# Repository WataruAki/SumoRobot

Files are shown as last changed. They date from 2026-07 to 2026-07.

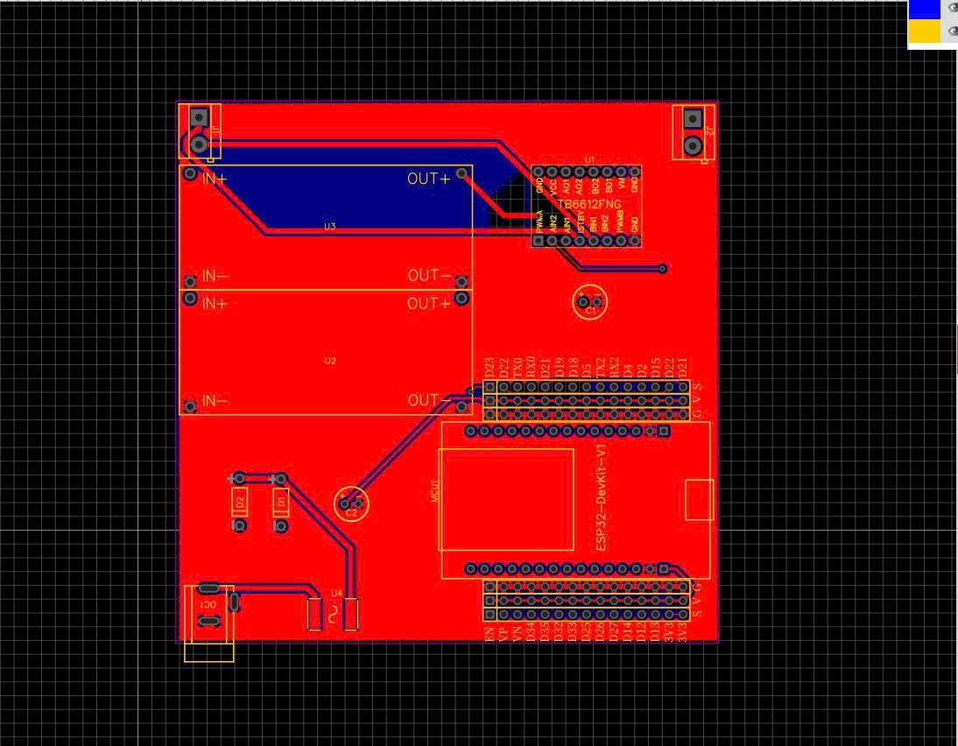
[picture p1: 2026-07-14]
hardware/SoDoMach.png

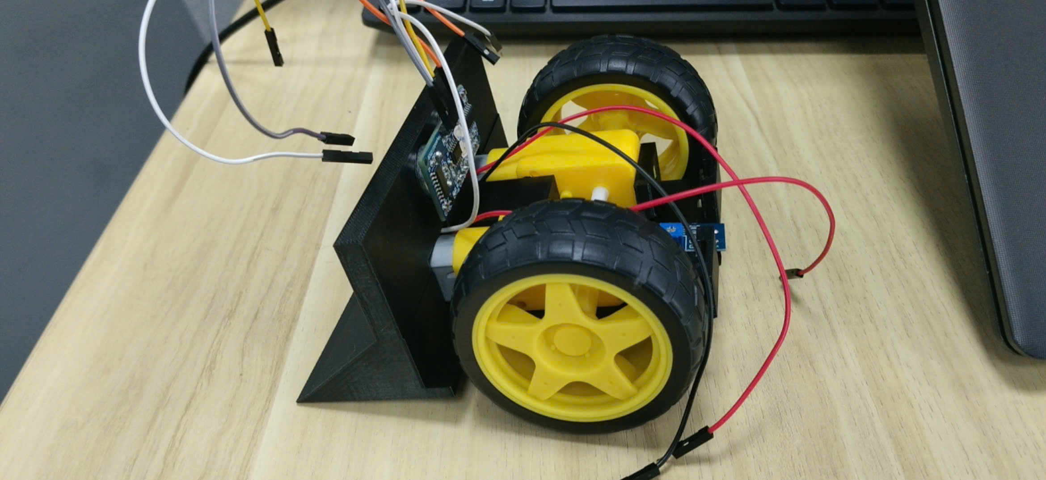
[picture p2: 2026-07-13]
docs/Minh hoa/A3.jpg

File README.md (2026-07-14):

# Sumo Robot 5-Phase - ESP32 + TB6612 + TT Motor

## Cau hinh nguon

- Pin 2S cap truc tiep vao VM cua TB6612.
- Mot LM2596 chinh 5.0 V chi cap cho ESP32 va cam bien.
- Tat ca GND noi chung.
- Khong cap chung hai motor qua LM2596 trong ban thi dau.
- ECHO cua HC-SR04 phai qua cau chia ap 5 V xuong 3.3 V.

## Anh xa GPIO

| Chuc nang | GPIO |
|---|---:|
| PWMA / AIN1 / AIN2 | 18 / 21 / 19 |
| PWMB / BIN1 / BIN2 | 5 / 22 / 23 |
| HC-SR04 TRIG / ECHO | 25 / 26 |
| Nut START | 27 |
| Cam bien bien truoc | 32 |
| TB6612 STBY | Noi co dinh 3V3 |

Kenh A duoc xem la motor trai, kenh B la motor phai. Neu mot ben quay nguoc, doi
`INVERT_LEFT_MOTOR` hoac `INVERT_RIGHT_MOTOR` thanh `true`.

## Switch RUN/STOP

- OFF = GPIO27 HIGH: cat PWM ngay va reset may trang thai ve `WAIT_START`.
- ON = GPIO27 LOW on dinh 35 ms: bat dau lai pha 1 va dem du 5 giay.
- OFF khong chi la lenh START nua; no la kill switch phan mem trong moi pha.
- Truoc khi reset/cap nguon, de switch OFF. Sau hieu lenh moi gat ON.

Serial khi gat OFF trong luc dang chay:

```text
[SWITCH OFF] Da cat motor va reset ve WAIT_START.
```

## Nam pha chinh

1. `PHASE_1_PROBING`: dung yen 5 giay, thu mau sieu am va tinh trung vi.
2. `PHASE_2_JUKE`: ne trai/phai co phan hoi, can 3 lan mat muc tieu moi dung.
3. `PHASE_3_RELOCK`: xoay tim, doi huong sau 420 ms, timeout 900 ms.
4. `PHASE_4_STRIKE`: tiep can, thu tiep xuc 100 ms, burst 80 ms.
5. `PHASE_5_RING_CONTROL`: bam muc tieu, chong neo, danh suon va thoat bien.

## Adaptive Extreme (van chi 5 pha)

- Loc median 3 mau sieu am de giam xung nhay/phan xa gia.
- Uoc luong toc do ap sat theo cm/s tu cac mau raw lien tiep.
- Can 2 mau charge lien tiep moi kich hoat ne, tranh phan ung voi mot mau nhieu.
- Khi doi thu lao nhanh trong 16-45 cm, ne trai/phai 90-140 ms roi khoa lai.
- Co cooldown 650 ms de doi thu khong the dung dong tac gia lam robot ne lien tuc.
- Random co gioi han thoi gian juke, search, contact test, burst va flank arc.
- Cac gioi han PWM, timeout motor va uu tien cam bien bien khong thay doi.

Day la cac trang thai con nam trong pha 5, khong phai them pha thu 6.

## Cam bien line - quyen uu tien cao nhat

- GPIO32 dung `INPUT_PULLUP`, cam bien nen cap 3V3.
- Khi khoi dong, dat robot de cam bien nam tren phan SAN DEN.
- Code lay 80 mau de hoc muc san den va tu suy ra muc vach trang doi nghich.
- Neu tin hieu dao qua 6 lan trong luc calibration, code bao loi va dung muc fallback.
- Gap vach thi ngat chien thuat ngay lap tuc, khong debounce de tranh bo lo vach 2.5 cm.
- Chi roi trang thai thoat bien sau khi da roi vach on dinh 20 ms.

Serial khoi dong dung phai co dang:

```text
[LINE] OK: floor=1, white=0, transitions=0.
```

Neu robot khoi dong khi cam bien dang nam tren vach trang, calibration se bi dao va
robot co the xem san den la vach. Luon dat tren san den truoc khi cap nguon/reset.

## Chien thuat chong neo / quat hut

- Tiep can o PWM 175.
- Tai khoang cach tiep xuc, thu day 100 ms o PWM 190.
- Burst them 80 ms o PWM 205.
- Neu muc tieu van sat dau xe, khong ghe motor: lui 65 ms.
- Chay cung danh suon 220 ms, luan phien trai/phai.
- Sau cung danh suon, quay lai pha khoa muc tieu.

Khong co encoder/cam bien dong nen day la phan loai bao thu. Robot xem tinh huong
"muc tieu van sat sau 180 ms" la nguy co neo, khong phai bang chung chac chan.

## Gioi han PWM voi pin 2S

- Search: 90
- Juke: 190
- Approach: 175
- Contact test: 190
- Attack burst: 205 trong toi da 80 ms
- Escape: 160
- Flank arc: 75 / 185

PWM 255 chi duoc dung cho short-brake cua TB6612, khong dung de keo TT lien tuc.

## Serial debug

Mo Serial Monitor o 115200 baud. Code in trang thai moi 300 ms, khong in moi
vong loop de tranh lam cham robot.

Vi du:

```text
[DBG] t=8350 state=P3_RELOCK sub=- US=24cm seen/lost=2/0 close=85cm/s charge=1 edgeRaw/white=1/0 start=0 motorL/R=90/-90
```

- `state`: pha hien tai.
- `sub`: trang thai con cua pha 4/5.
- `US`: khoang cach sieu am gan nhat; `-1` la timeout.
- `seen/lost`: so mau thay/mat lien tiep.
- `close`: toc do ap sat uoc luong; so duong la dang tien gan.
- `charge`: 1 khi da xac nhan doi thu lao nhanh.
- `edgeRaw/white`: muc raw hien tai / muc da hoc cho vach trang.
- `start`: muc logic cong tac START; ON thuong la 0.
- `motorL/R`: lenh PWM co dau cua motor trai/phai.

Dat `DEBUG_SERIAL=false` sau khi hieu chinh xong neu muon tat log dinh ky.

## Hieu chinh truoc tran

1. Chinh LM2596 = 5.0 V truoc khi cam ESP32.
2. Kiem tra hai banh tien dung chieu; sua hai bien `INVERT_*` neu can.
3. Dat robot cach vach, xac dinh `EDGE_WHITE_LEVEL` la `HIGH` hay `LOW`.
4. Cho luoi xuc vua cham vat, doc Serial va sua `CONTACT_DISTANCE_CM`.
5. Thu edge reverse tu toc do thap; giam `EDGE_REVERSE_MAX_MS` neu lui qua xa.
6. Thu flank arc khi robot o giua san; giam `FLANK_ARC_MS` neu cung qua rong.
7. Kiem tra pin day 8.4 V; motor va TB6612 khong duoc nong nhanh.
8. Khi nap code qua USB, tranh dong thoi cap nguon 5 V nguoc vao cong USB neu mach
   chua co power-ORing.

## Trang thai xac minh

Da kiem tra cu phap voi Arduino-ESP32 Core 2.x va 3.x. Code chi dung HC-SR04 de
phat hien doi thu, khong can thu vien ToF/I2C. Van can bien dich tren dung board
package va thu tai thuc te truoc thi dau.

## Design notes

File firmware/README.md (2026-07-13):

# Robot Sumo Tự Hành – ESP32 Firmware

Firmware điều khiển cho robot sumo tự hành (autonomous), chạy trên vi điều khiển ESP32. Sau khi bấm nút Start, robot hoạt động hoàn toàn tự động: dò tìm đối thủ bằng cảm biến khoảng cách, truy đuổi, tấn công đẩy, đồng thời tự né vạch biên trắng để không bị đẩy ra khỏi sân đấu.

## Mục lục
- [Tính năng chính](#tính-năng-chính)
- [Phần cứng yêu cầu](#phần-cứng-yêu-cầu)
- [Sơ đồ chân (Pinout)](#sơ-đồ-chân-pinout)
- [Thư viện cần cài đặt](#thư-viện-cần-cài-đặt)
- [Cấu hình trước khi nạp](#cấu-hình-trước-khi-nạp)
- [Nguyên lý hoạt động](#nguyên-lý-hoạt-động)
- [Nạp firmware & sử dụng](#nạp-firmware--sử-dụng)
- [Tinh chỉnh thông số](#tinh-chỉnh-thông-số)
- [Cấu trúc mã nguồn](#cấu-trúc-mã-nguồn)
- [Gỡ lỗi](#gỡ-lỗi-debug)
- [Giới hạn hiện tại](#giới-hạn-hiện-tại)

## Tính năng chính
- Máy trạng thái 7 pha mô phỏng chiến thuật thi đấu: chờ hiệu lệnh → dò tìm mở màn → né đòn đầu → khóa lại mục tiêu → tấn công → kiểm soát sân đấu
- Kết hợp cảm biến siêu âm HC-SR04 (bắt buộc) và ToF VL53L0X (tùy chọn, bật/tắt bằng một macro)
- Cơ chế **"anti-anchor"**: khi bị đối thủ ghì đứng yên, robot tự lùi ngắn rồi đánh vòng cung sang sườn thay vì cố đẩy thẳng mãi
- Tự động lùi + xoay né ngay khi cảm biến biên phát hiện vạch trắng ranh giới sân
- Ngẫu nhiên hóa chu kỳ quét siêu âm để giảm nhiễu chéo khi hai robot cùng dùng cảm biến siêu âm đối đầu nhau
- Debounce nút Start; log/telemetry chi tiết qua Serial để theo dõi và hiệu chỉnh

## Phần cứng yêu cầu
| Thành phần | Vai trò |
|---|---|
| Vi điều khiển ESP32 | Bắt buộc — dùng `esp_system.h` và API LEDC (`ledcAttach`/`ledcWrite`) |
| Cảm biến siêu âm HC-SR04 | Cảm biến khoảng cách chính để phát hiện đối thủ |
| Cảm biến ToF VL53L0X | Tùy chọn — cảm biến phụ tăng độ chính xác, bật qua macro `USE_VL53L0X` |
| Cảm biến vạch biên (ngõ ra số) | 1 cảm biến đặt chính giữa đầu robot, phát hiện vạch trắng ranh giới sân |
| Driver động cơ đôi kiểu TB6612FNG (hoặc tương đương) | Mỗi kênh gồm 1 chân PWM + 2 chân điều khiển chiều IN1/IN2 |
| 2 động cơ DC (bánh trái/phải) | Truyền động |
| Nút nhấn Start | Đấu `INPUT_PULLUP`, nhấn = mức LOW |

## Sơ đồ chân (Pinout)

| Chức năng | Hằng số | GPIO |
|---|---|---|
| Nút Start | `PIN_START_BUTTON` | 27 |
| Siêu âm – Trig | `PIN_US_TRIG` | 25 |
| Siêu âm – Echo | `PIN_US_ECHO` | 26 |
| ToF VL53L0X – SDA | `PIN_TOF_SDA` | 33 |
| ToF VL53L0X – SCL | `PIN_TOF_SCL` | 13 |
| Động cơ trái – PWM | `PIN_LEFT_PWM` | 18 |
| Động cơ trái – IN1 | `PIN_LEFT_IN1` | 21 |
| Động cơ trái – IN2 | `PIN_LEFT_IN2` | 19 |
| Động cơ phải – PWM | `PIN_RIGHT_PWM` | 5 |
| Động cơ phải – IN1 | `PIN_RIGHT_IN1` | 22 |
| Động cơ phải – IN2 | `PIN_RIGHT_IN2` | 23 |
| Cảm biến biên (giữa) | `PIN_EDGE_CENTER` | 32 |

> Cảm biến biên báo "phát hiện vạch trắng" ở mức `HIGH` (hằng số `EDGE_WHITE_LEVEL`). Nếu cảm biến của bạn xuất mức ngược lại, đổi hằng số này thành `LOW`.
>
> Nếu một bên động cơ quay ngược chiều mong muốn khi test thực tế, chỉnh `INVERT_LEFT_MOTOR` / `INVERT_RIGHT_MOTOR` thành `true` thay vì đấu lại dây động cơ.

## Thư viện cần cài đặt
- **Arduino-ESP32 core** (board package cho ESP32) — code tự nhận diện phiên bản core qua `ESP_ARDUINO_VERSION_MAJOR` để gọi đúng API LEDC (core v3+ dùng `ledcAttach`, core v2.x dùng `ledcSetup`/`ledcAttachPin`), nên tương thích cả hai dòng core phổ biến
- **Thư viện `VL53L0X`** (Pololu) — chỉ cần cài nếu bật cảm biến ToF

## Cấu hình trước khi nạp
Đầu file `Firmware.ino` có các macro/hằng số nên kiểm tra trước khi build:

```cpp
#define USE_VL53L0X 0   // đổi thành 1 nếu robot có gắn cảm biến ToF VL53L0X
```

```cpp
constexpr bool INVERT_LEFT_MOTOR  = false;
constexpr bool INVERT_RIGHT_MOTOR = false;
```

Nếu giữ `USE_VL53L0X 0`, firmware chỉ dùng cảm biến siêu âm và không cần cài thư viện VL53L0X.

## Nguyên lý hoạt động
Robot vận hành theo máy trạng thái chính gồm 7 pha:

```mermaid
stateDiagram-v2
    [*] --> WAIT_START
    WAIT_START --> PHASE_1_PROBING: nhấn nút Start
    PHASE_1_PROBING --> PHASE_2_JUKE: hết 5s dò tìm mở màn
    PHASE_2_JUKE --> PHASE_2_BRAKE: mất dấu hoặc hết giờ né
    PHASE_2_BRAKE --> PHASE_3_RELOCK: hết thời gian phanh ngắn
    PHASE_3_RELOCK --> PHASE_4_STRIKE: khóa được mục tiêu
    PHASE_3_RELOCK --> PHASE_5_RING_CONTROL: hết giờ khóa lại (900ms)
    PHASE_4_STRIKE --> PHASE_5_RING_CONTROL: kết thúc chu trình tấn công
    PHASE_5_RING_CONTROL --> PHASE_3_RELOCK: xong pha đánh sườn (anti-anchor)

    note right of PHASE_5_RING_CONTROL
        Chạm vạch biên (từ Phase 2 trở đi)
        đều nhảy về đây để lùi + xoay
        thoát biên trước khi dò tiếp
    end note
```

**1. `WAIT_START`** — Đứng yên, liên tục kiểm tra nút Start (debounce 35ms). Đây là lúc chờ trọng tài hô hiệu lệnh.

**2. `PHASE_1_PROBING`** (5 giây cố định) — Đứng yên tại chỗ, trong lúc đó liên tục quét siêu âm (và ToF nếu bật) với chu kỳ ngẫu nhiên 45–70ms để tránh nhiễu chéo. Cuối pha, tính khoảng cách trung vị (median) và % độ tin cậy để xác định có đối thủ phía trước hay không, đồng thời chọn ngẫu nhiên hướng né ban đầu (trái/phải).

**3. `PHASE_2_JUKE` → `PHASE_2_BRAKE`** — Xoay né nhanh (pivot quanh một bánh) sang hướng đã chọn để tránh cú lao đầu tiên của đối thủ. Dừng né khi cảm biến xác nhận mất dấu đối thủ (3 lần đo liên tiếp không thấy) hoặc khi chạm mốc thời gian tối đa, sau đó phanh chủ động (counter-brake) trong 15ms để triệt tiêu đà quay trước khi dò tìm lại.

**4. `PHASE_3_RELOCK`** — Xoay quét tìm lại mục tiêu: quét theo hướng đã định trong 420ms đầu, sau đó đổi hướng nếu vẫn chưa thấy. Thấy đối thủ đủ số mẫu liên tiếp (2 lần) → khóa mục tiêu, chuyển Phase 4. Quá 900ms không khóa được → chuyển Phase 5 để tìm kiếm rộng hơn.

**5. `PHASE_4_STRIKE`** — Tiến thẳng lại gần mục tiêu đã khóa; khi đủ gần (≤14cm) sẽ thử chạm nhẹ (contact test) trong 100ms để xác nhận, rồi bung lực đẩy mạnh (attack burst) trong 80ms nếu vẫn còn giữ khoảng cách chạm (≤17cm). Sau đòn đẩy: nếu đối thủ vẫn còn kề sát (bị ghì, không lùi) → chuyển sang Phase 5 ở trạng thái con đánh sườn (anti-anchor); nếu mất mục tiêu hoặc hết giờ giới hạn 650ms → cũng rơi về Phase 5 để dò tìm lại.

**6. `PHASE_5_RING_CONTROL`** — Pha "kiểm soát sân đấu" tổng quát, có 7 trạng thái con:

| Trạng thái con | Mô tả |
|---|---|
| `P5_REGULAR_TRACKING` | Xoay quét tìm mục tiêu; thấy thì tiến lại gần, đủ gần thì chuyển sang chạm thử |
| `P5_CONTACT_TEST` | Đẩy nhẹ thử chạm để xác nhận đối thủ thực sự ở trước mặt |
| `P5_ATTACK_BURST` | Bung lực đẩy mạnh trong thời gian ngắn |
| `P5_ANCHOR_ESCAPE` | Lùi nhanh để thoát tình trạng bị ghì đứng yên (đẩy mãi không đi) |
| `P5_FLANK_ARC` | Đánh vòng cung sang một bên sườn đối thủ rồi quay lại khóa mục tiêu ở Phase 3 |
| `P5_EDGE_REVERSING` | Lùi ra khỏi vạch trắng biên sân (có xác nhận đã sạch vạch) |
| `P5_EDGE_TURNING` | Xoay hướng ra xa biên trước khi quay lại dò tìm mục tiêu |

Ngoài ra, nếu vừa thấy mục tiêu rồi mất dấu đột ngột trong lúc tracking, robot sẽ "lao thẳng dự đoán" (**blind rush**, 70ms) theo quán tính trước khi chuyển sang quét tìm, thay vì dừng lại ngay lập tức.

**Ưu tiên an toàn:** kể từ khi robot bắt đầu di chuyển (Phase 2 trở đi), cảm biến biên luôn được kiểm tra trước tiên ở từng bước xử lý. Hễ phát hiện vạch trắng, robot ngắt ngay hành vi hiện tại, lùi ra xa vạch (có xác nhận đã sạch vạch), rồi xoay hướng thoát ra — hướng xoay đổi luân phiên mỗi lần để không lặp lại đúng một góc bị kẹt — trước khi quay lại dò tìm đối thủ. Riêng `WAIT_START` và 5 giây `PHASE_1_PROBING`, robot đứng yên hoàn toàn nên không cần kiểm tra biên.

## Nạp firmware & sử dụng
1. Mở `Firmware.ino` bằng Arduino IDE (hoặc PlatformIO)
2. Cài board package ESP32 nếu chưa có, chọn đúng board trong menu Tools → Board
3. Chọn đúng cổng COM (cài driver USB-to-serial nếu cần)
4. (Tùy chọn) Cài thư viện `VL53L0X` và sửa `USE_VL53L0X` thành `1` nếu robot có cảm biến ToF
5. Nạp firmware
6. Mở Serial Monitor, tốc độ **115200 baud**, để theo dõi log
7. Đặt robot vào sân, chờ hiệu lệnh trọng tài rồi nhấn nút Start — robot tự đứng yên đúng 5 giây trước khi bắt đầu di chuyển

## Tinh chỉnh thông số
Toàn bộ tham số thời gian (ms) và tốc độ PWM (0–255) được khai báo `constexpr` ở đầu file, có thể chỉnh trực tiếp mà không ảnh hưởng logic chương trình:

| Nhóm | Ví dụ hằng số | Ý nghĩa |
|---|---|---|
| Ngưỡng khoảng cách hợp lệ | `US_MIN_CM`/`US_MAX_CM`, `TOF_MIN_MM`/`TOF_MAX_MM` | Vùng khoảng cách được xem là "có đối thủ" |
| Ngưỡng chạm/tấn công | `CONTACT_DISTANCE_CM`, `CONTACT_HOLD_DISTANCE_CM` | Khoảng cách kích hoạt chạm thử / giữ đẩy |
| Thời lượng từng hành vi | `JUKE_MIN_MS`/`MAX_MS`, `STRIKE_TOTAL_TIMEOUT_MS`, `RELOCK_TIMEOUT_MS`, `FLANK_ARC_MS`... | Giới hạn thời gian mỗi hành vi |
| Tốc độ động cơ | `PWM_SEARCH`, `PWM_APPROACH`, `PWM_ATTACK_BURST`, `PWM_FLANK_SLOW`/`FAST`... | Tốc độ PWM cho từng hành vi cụ thể |

Các giá trị này phụ thuộc nhiều vào ma sát mặt sân, công suất động cơ và điện áp pin thực tế, nên cần tinh chỉnh dần và thử trực tiếp trên sân thi đấu.

## Cấu trúc mã nguồn
| Nhóm chức năng | Hàm liên quan |
|---|---|
| Điều khiển động cơ | `setMotor`, `shortBrakeMotor`, `setupMotorPwm`, `writeMotorPwm`, `motorsDrive`, `stopMotors`, `executeJuke`, `executeCounterBrake`, `executeSearchTurn` |
| Đọc cảm biến thô | `readUltrasonicCm`, `readToFMm`, `edgeDetected`, `startButtonPressed` |
| Thống kê Phase 1 | `resetTelemetry`, `collectPhase1`, `finalizePhase1`, `medianOf`, `printTelemetry` |
| Cảm biến khi giao chiến (Phase 3–5) | `resetCombatObservation`, `updateCombatSensors`, `combatTargetSeen`, `combatDistanceCm` |
| Xử lý từng pha | `handlePhase3`, `handlePhase4`, `handlePhase5`, `enterEdgeEscape` |

## Gỡ lỗi (Debug)
Mở Serial Monitor ở **115200 baud**. Log được in dạng `[NHÃN] nội dung`, một số nhãn tiêu biểu:
- `[SAN SANG]`, `[PHASE 1]`, `[PHASE 2]`, `[PHASE 3]`, `[PHASE 3 -> 4]`, `[PHASE 4 -> 5]` — chuyển pha
- `[BIEN]` — phát hiện/thoát vạch biên sân
- `[ANTI-ANCHOR]` — kích hoạt/kết thúc pha đánh sườn khi bị ghì
- `[LOI]` — lỗi khởi tạo PWM hoặc không tìm thấy cảm biến ToF

Cuối `PHASE_1_PROBING`, firmware in bảng telemetry: số mẫu siêu âm/ToF hợp lệ trên tổng số lần đo, có phát hiện đối thủ hay không, % độ tin cậy, khoảng cách trung vị và hướng né đã chọn — rất hữu ích để kiểm tra cảm biến trước khi thi đấu.

## Giới hạn hiện tại
- Chỉ có **một** cảm biến biên đặt giữa robot, không phân biệt được vạch biên nằm bên trái hay bên phải khi chạm, nên phản ứng thoát biên luôn theo một kiểu lùi + xoay cố định
- Các cú xoay (search turn, edge turn...) là **điều khiển theo thời gian** (time-based, vòng hở), không có hồi tiếp từ IMU/encoder, nên góc xoay thực tế có thể lệch theo điện áp pin và độ ma sát mặt sân
- Cảm biến ToF VL53L0X chỉ là tùy chọn (mặc định tắt); khi tắt, mọi quyết định hoàn toàn dựa vào cảm biến siêu âm

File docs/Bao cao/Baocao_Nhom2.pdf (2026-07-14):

## ĐẠI HỌC QUỐC GIA HÀ NỘI

## Trường Đại học Việt Nhật

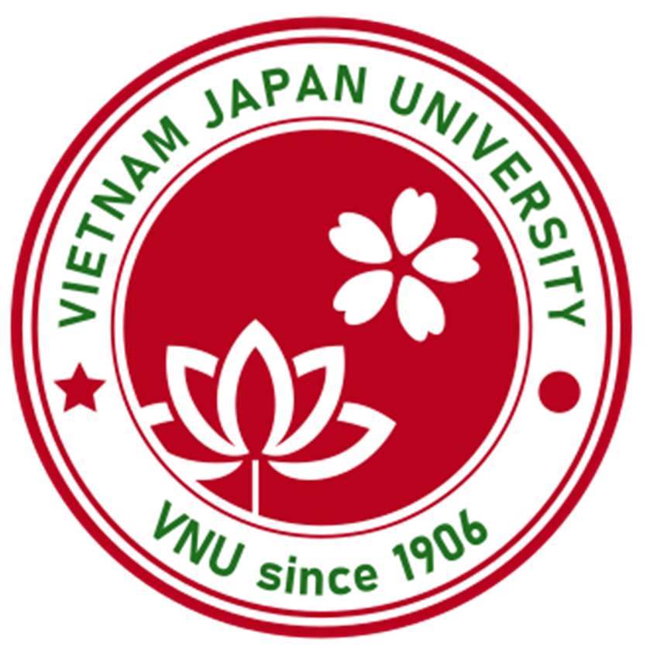
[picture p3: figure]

## BÁO CÁO BÀI THI KẾT THÚC HỌC PHẦN

## Môn: Thí nghiệm trong khoa học kĩ thuật 1

Giảng viên hướng dẫn: TS. Bùi Huy Kiên, MSc. Nguyễn Tiến Đạt

## Nhóm 2

Danh sách thành viên
1. 25112007 - Hoàng Việt Anh - Nhóm trưởng
2. 25112001 - Lê Văn Thái An
3. 25112002 - Dương Hoàng An
4. 25119064 - Lê Văn Trường

2

# Mục lục

3

4

## Lời nói đầu

Trong kỷ nguyên công nghiệp 4.0, hệ thống nhúng và Internet vạn vật đang ngày càng khẳng định vị thế cốt lõi trong việc thay đổi bộ mặt công nghệ toàn cầu. Để thích ứng và làm chủ những công nghệ tiên tiến này, việc thu hẹp khoảng cách giữa lý thuyết giảng đường và thực tiễn sản xuất là vô cùng cấp thiết. Nhận thức được tầm quan trọng đó, học phần Thí nghiệm trong Khoa học và Kỹ thuật 1 tại Trường Đại học Việt Nhật đã mang đến dự án cuối kỳ “Sumo Robot Challenge”. Đây không chỉ là một bài kiểm tra kiến thức thông thường, mà còn là một thử thách kỹ thuật toàn diện, đòi hỏi sinh viên phải tự tay trải nghiệm toàn bộ quy trình phát triển một sản phẩm công nghệ từ con số không.
Báo cáo kỹ thuật này là kết quả sau hơn một tháng nỗ lực nghiên cứu, thử nghiệm và hoàn thiện của nhóm. Thông qua việc chế tạo một robot tự hành tham gia thi đấu sumo, nhóm đã có cơ hội quý báu để cọ xát với thực tế: từ việc tối ưu hóa cấu trúc cơ khí bằng công nghệ in 3D/cắt laser, thiết kế sơ đồ nguyên lý mạch phần cứng, mạch nguồn pin Li-ion 2S, cho đến việc lập trình thuật toán máy trạng thái phức tạp nhằm điều khiển robot vận hành một cách thông minh, tự động hoàn toàn. Quá trình triển khai dự án không chỉ giúp chúng em củng cố sâu sắc chuyên môn kỹ thuật mà còn rèn luyện được các kỹ năng mềm thiết yếu để giải quyết các bài toán phát sinh trong thực tế.
Để có thể hoàn thành sản phẩm và bài báo cáo này một cách trọn vẹn, nhóm nghiên cứu xin được gửi lời cảm ơn sâu sắc nhất đến thầy TS. Bùi Huy Kiên và anh MSc. Nguyễn Tiến Đạt. Sự tận tình trong công tác giảng dạy, cùng những định hướng chuyên môn, góp ý kỹ thuật sắc bén của thầy và anh trong suốt các tuần học đã giúp nhóm vượt qua nhiều rào cản công nghệ lớn để đưa sản phẩm đi đúng hướng.
Dù đã dành nhiều thời gian đầu tư và chuẩn bị nghiêm túc, song do giới hạn về mặt thời gian cũng như kinh nghiệm thực tế, báo cáo chắc chắn không tránh khỏi những thiếu sót nhất định. Nhóm rất mong sẽ nhận được những ý kiến đóng góp, nhận xét từ thầy và anh để sản phẩm cũng như kiến thức của nhóm được hoàn thiện hơn nữa. Trân trọng cảm ơn

5

I. GIỚI THIỆU & ĐẶT VẤN ĐỀ

### 1. Bối cảnh dự án

Sumo Robot Challenge là bài tập lớn cuối học phần thí nghiệm trong khoa học và kĩ thuật 1. Nhiệm vụ của nhóm là thiết kế, chế tạo một robot tự hành hoàn chỉnh và tham gia thi đấu nhằm mục đích đẩy robot đối thủ ra khỏi sàn đấu tròn theo luật

### 2. Mục tiêu

- Cơ khí: Thiết kế, gia công khung bằng in 3D/cắt laser; tối ưu hóa trọng tâm và lực bám.
- Phần cứng: Thiết kế mạch nguồn , mạch điều khiển động cơ và tích hợp các cảm biến.
- Phần mềm: Lập trình vi điều khiển theo mô hình máy trạng thái, giúp robot tự động dò biên viền trắng và tấn công/phòng thủ khi phát hiện đối thủ.
- Kỹ năng: Quản lý mã nguồn qua GitHub, làm việc nhóm và viết báo cáo kỹ thuật.

### 3. Ràng buộc kỹ thuật

- Kích thước & Khối lượng: Diện tích chân đế khởi đầu bé hơn 12x12, khối lượng tổng bé hơn 700g
- Nguồn điện: Bắt buộc sử dụng 2 cell pin Li-ion/LiPo mắc nối tiếp (7.4 V), cấm mạch tăng áp hoặc nguồn ngoài.
- Vận hành: Tự hành hoàn toàn dựa trên cảm biến dò biên hướng xuống và cảm biến phát hiện đối thủ; cấm điều khiển bằng tay.
- An toàn: Cấm các cơ cấu gây phá hủy, gây nhiễu, hoặc sử dụng vật liệu nguy hiểm.
II. TỔNG QUAN & NGHIÊN CỨU LIÊN QUAN

### 1. Tổng quan về thể thức thi đấu Mini-Sumo

- Sàn đấu : Mặt phẳng hình tròn bằng gỗ MDF hoặc mica sơn, đường kính tiêu chuẩn 77 cm. Mặt sân được sơn màu đen nhám ít phản xạ và bao quanh bởi một vạch viền màu trắng rộng 2.5 cm ở mép ngoài cùng để làm mốc định vị biên cho cảm biến quang học.

6

- Luật thi đấu đối kháng: Hai robot đối đầu trực tiếp theo thể thức loại trực tiếp. Mỗi trận đấu diễn ra tối đa trong 3 hiệp (mỗi hiệp tối đa 3 phút). Robot giành chiến thắng 1 hiệp khi đẩy được đối thủ ra khỏi vạch trắng hoặc đối thủ tự di chuyển ra ngoài sàn đấu.
- Yêu cầu khởi động: Sau khi có hiệu lệnh của trọng tài và người điều khiển nhấn nút kích hoạt, robot bắt buộc phải cấu hình một khoảng thời gian trễ đúng 5 giây trước khi chính thức di chuyển.

### 2. Cơ sở lý thuyết

a. Thiết kế cơ khí
Ta có công thức vật lí cổ điển:
F ≤ μ ⋅ N = μ ⋅ m ⋅ g
Trong đó:
- μ: Hệ số ma sát giữa bánh xe và mặt sàn Dohyo.
- m: Khối lượng toàn bộ của robot (∼ 700 g).
- g: Gia tốc trọng trường.

Để tối đa hóa lực đẩy, bên cạnh việc lựa chọn vật liệu lốp có hệ số ma sát μ cao, giải pháp cơ khí tối ưu là phải hạ trọng tâm xuống sát mặt sàn nhất có thể nhằm tránh hiện tượng mô-men lực làm lật hoặc nhấc bổng robot khi va chạm trực diện. Khung vỏ được vẽ trên CAD và chế tạo bằng công nghệ in 3D kết hợp cắt laser giúp cấu trúc bền bỉ, hấp thụ xung lực tốt.
b. Kiến trúc phần cứng và mạch động lực

Hệ thống điện tử trên robot Sumo được xây dựng xung quanh chip xử lý trung tâm hiệu năng cao ESP32, kết hợp với hệ thống điều khiển công suất:
- Khối nguồn : Robot sử dụng hệ thống pin Li-ion 2S mắc nối tiếp. Hệ thống mạch nguồn được bọc bảo vệ cách điện tuyệt đối nhằm tránh nguy cơ ngắn mạch hoặc cháy nổ khi va chạm mạnh.
- Khối điều khiển động cơ: Sử dụng IC điều khiển động cơ DC dòng cao tích hợp chân chân kích hoạt và chế độ chờ. Vi điều khiển sử dụng chức năng điều xung ledc của ESP32 ở tần số cao 20 kHz với độ phân giải 8-bit

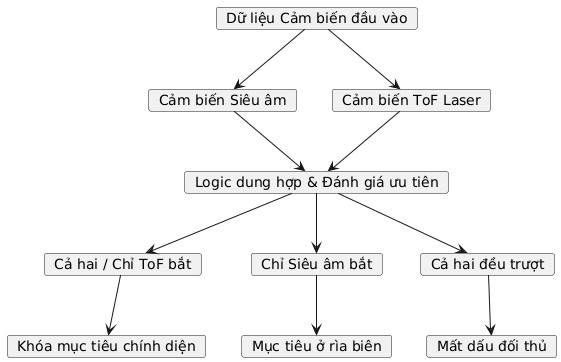
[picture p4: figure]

7

nhằm triệt tiêu tiếng rít dòng điện, giúp điều khiển tốc độ và đảo chiều động cơ.
c. Dung hợp cảm biến

Để khắc phục nhược điểm vật lý của từng loại cảm biến đơn lẻ trong môi trường thi đấu động, hệ thống sử dụng kiến trúc radar kép phối hợp:
- Cảm biến siêu âm: Đo khoảng cách góc rộng (ngưỡng hoạt động 60 cm). Ưu điểm là vùng phủ lớn nhưng độ chính xác kém và tần số lấy mẫu chậm.
- Cảm biến ToF Laser VL53L0X: Đo khoảng cách bằng thời gian bay của chùm laser tập trung (ngưỡng hoạt động 600 mm). Ưu điểm là tốc độ lấy mẫu rất cao và góc quét hẹp, đóng vai trò khóa mục tiêu ở chính diện.
- Logic dung hợp: Hệ thống đánh giá dữ liệu theo thứ tự ưu tiên: Nếu cả hai hoặc chỉ có ToF phát hiện, mục tiêu được xác định ở trạng thái khóa chính diện. Nếu chỉ có siêu âm phát hiện, mục tiêu đang nằm ở mép trái/phải. Khi cả hai đều trượt, hệ thống ghi nhận mất dấu .
d. Thuật toán trạng thái & Chiến thuật thi đấu
- Đòn nhử đầu hiệp: Ngay khi kết thúc 5 giây đếm ngược, thay vì lao thẳng trực diện, robot thực hiện pha bẻ lái chớp nhoáng. Hướng bẻ lái được thuật toán

8

chọn ngẫu nhiên để đối thủ không thể bắt bài ở các hiệp sau. Một bánh sẽ khóa hãm, bánh còn lại chạy với tốc độ cao. Đòn này lợi dụng quán tính lao tới của đối phương để lách né, đồng thời mở góc để robot phản công từ mạn sườn. Đáng chú ý, cơ chế an toàn dò vạch trắng vẫn được giữ mức ưu tiên cao nhất ngay trong pha né tránh để đảm bảo robot không vô tình tự lùi ra khỏi sân.
- Quét tìm kiếm chống nhiễu: Khi mất dấu mục tiêu, robot duy trì tốc độ xoay ổn định kết hợp đảo chiều định kỳ. Để triệt tiêu hiện tượng cộng hưởng nhiễu sóng siêu âm từ các robot khác phát ra, hệ thống áp dụng cơ chế nhiễu thời gian: chu kỳ phát xung ping lấy mẫu không cố định mà biến thiên ngẫu nhiên trong khoảng 30 - 42 ms. Việc này giúp làm sạch luồng dữ liệu đầu vào trước khi đưa qua hệ thống lọc.
- Rà góc và khóa mục tiêu: Tốc độ quét được thiết lập ở mức thấp chính là chìa khóa để triệt tiêu quán tính cơ học, giúp hệ thống không trượt lố qua mục tiêu. Khi cảm biến phát hiện vật thể, robot không vội vã tấn công mà yêu cầu một chuỗi xác nhận dữ liệu liên tiếp
- Gia tốc theo từng bậc chiến thuật : Khi mục tiêu bị khóa, robot không đột ngột tăng ga tối đa (255) ngay lập tức để tránh hiện tượng trượt bánh hoặc bốc đầu làm hổng lưỡi ủi. Thuật toán kiểm soát lực bám đường bằng cách chia sức mạnh theo từng bậc thực chiến: tiếp cận với tốc độ vừa, tăng lực tạo đà khi bắt đầu va chạm, và chỉ bùng nổ công suất ép tối đa khi cảm biến xác nhận khoảng cách dính chập.
- Cơ chế ngắt mềm dò biên ưu tiên cao: Để đảm bảo tính ổn định cao nhất cho hệ thống lõi ESP32 và tránh xung đột bộ nhớ do điều khiển động cơ bằng ngắt phần cứng, firmware sử dụng vòng lặp ưu tiên. Lệnh kiểm tra vạch trắng edgeDetected() luôn được đặt ở vị trí đầu tiên của mọi chu trình chiến đấu. Ngay khi phát hiện mép sàn, cờ hiệu lập tức kích hoạt, buộc robot hủy mọi tác vụ tấn công hiện tại để lùi khẩn cấp và bẻ góc hướng trở lại vùng trung tâm an toàn.
III. THIẾT KẾ TỔNG THỂ & PHẦN CỨNG

### 1. Thiết kế tổng thể hệ thống:

Hệ thống điều khiển Sumo Robot được cấu trúc thành một vòng lặp kín bao gồm 4 khối chức năng chính hoạt động xoay quanh vi điều khiển trung tâm ESP32:

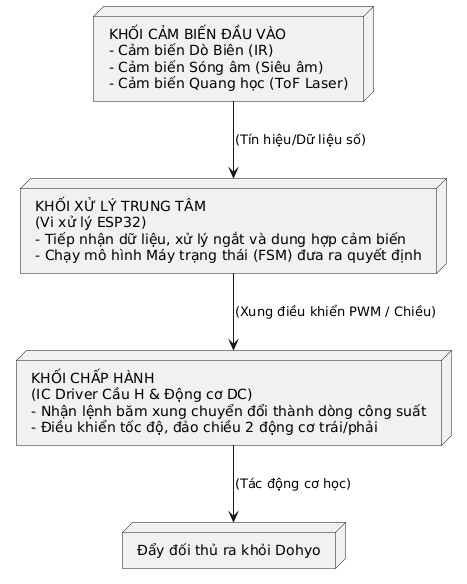
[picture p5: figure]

9

- Khối xử lý trung tâm: Đóng vai trò là “não bộ” tiếp nhận dữ liệu từ khối cảm biến, thực hiện thuật toán dung hợp dữ liệu và máy trạng thái để xuất xung điều khiển động cơ.
- Khối cảm biến: Bao gồm radar kép (Cảm biến siêu âm + ToF Laser) để phát hiện vật thể và cảm biến hồng ngoại phản xạ (IR) để phát hiện vạch biên.
- Khối chấp hành: Bao gồm IC cầu H điều khiển động cơ DC băm xung PWM và chân kích hoạt standby.
- Khối nguồn và giao tiếp ngoại vi: Pin Li-ion 2S, mạch hạ áp, nút nhấn khởi động và cổng nạp.

### 2. Thiết kế chi tiết phần cứng & Sơ đồ nối dây

10

a. Cấu hình chân vi điều khiển
STT | Chân trên mạch | GPIO | Chức năng | Ghi chú
1 | PIN_AIN1 | 25 | Điều khiển chiều quay Động cơ Trái (Hướng 1) | Kết nối khối Driver
2 | PIN_AIN2 | 26 | Điều khiển chiều quay Động cơ Trái (Hướng 2) | Kết nối khối Driver
3 | PIN_PWMA | 27 | Phát xung PWM điều khiển tốc độ Động cơ Trái | Tần số băm xung 20 kHz
4 | PIN_BIN1 | 14 | Điều khiển chiều quay Động cơ Phải (Hướng 1) | Kết nối khối Driver
5 | PIN_BIN2 | 12 | Điều khiển chiều quay Động cơ Phải (Hướng 2) | Kết nối khối Driver
6 | PIN_PWMB | 13 | Phát xung PWM điều khiển tốc độ Động cơ Phải | Tần số băm xung 20 kHz
7 | PIN_STBY | 33 | Kích hoạt hoặc ngắt chế độ chờ (Standby) của Driver | Logic HIGH để hoạt động
8 | PIN_LINE | 32 | Nhận tín hiệu số đầu vào từ cảm biến dò biên | Cấu hình ngắt phần cứng (ISR)
9 | I2C_SDA | 21 | Đường truyền dữ liệu số (Data) giao tiếp I2C | Kết nối cảm biến ToF VL53L0X
10 | I2C_SCL | 22 | Đường cấp xung nhịp (Clock) giao tiếp I2C | Kết nối cảm biến ToF VL53L0X
11 | PIN_US_TRIG | 5 | Phát xung kích hoạt đầu phát sóng siêu âm | Phát xung mức cao thời gian 10 µs
12 | PIN_US_ECHO | 18 | Thu nhận xung phản hồi tính thời gian sóng âm | Đo thời gian bằng hàm pulseIn
13 | PIN_BTN_START | 4 | Nút nhấn cơ học kích hoạt hệ thống | Khởi động chu trình đếm ngược 5 giây

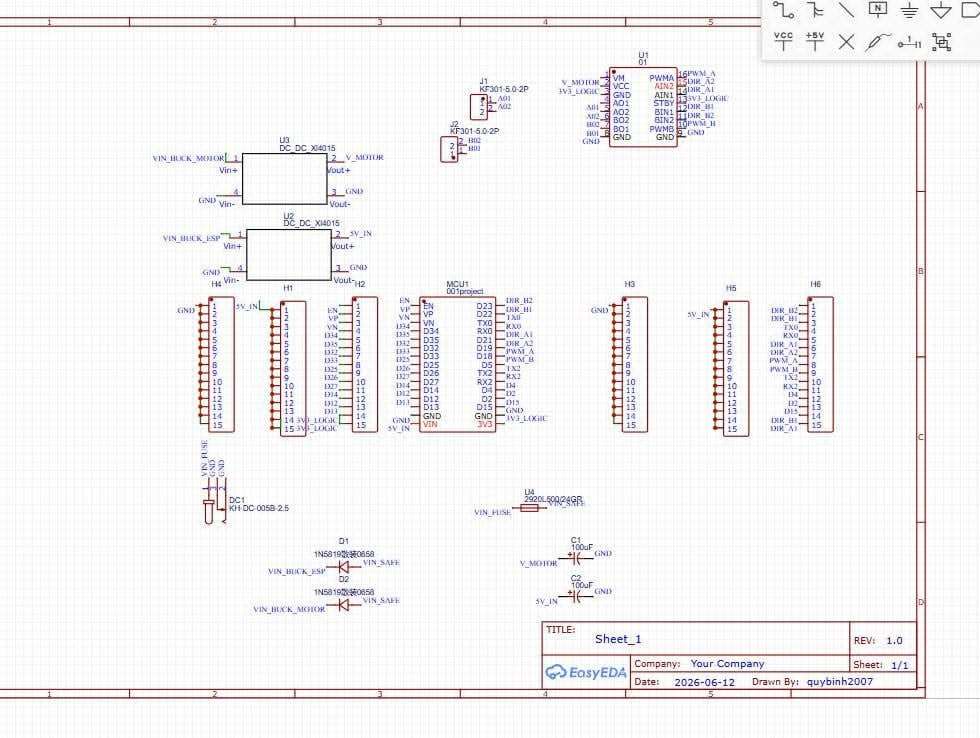
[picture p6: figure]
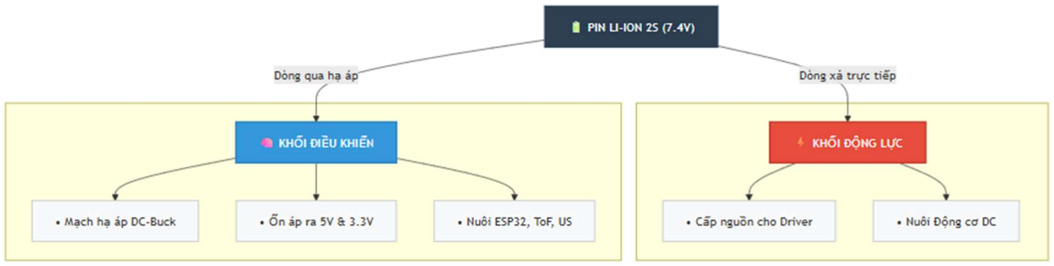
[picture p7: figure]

11

Ảnh: Sơ đồ mạch
b. Thiết kế mạch nguồn an toàn

Hệ thống nguồn tuân thủ nghiêm ngặt quy định sử dụng 2 cell pin Li-ion 18650 mắc
nối tiếp, cung cấp điện áp danh định 7.4 V (Đầy tải đạt 8.4 V). - | Đường nguồn động lực: Nguồn từ pin được dẫn trực tiếp tới chân cấp nguồn
| công suất của IC Driver để nuôi động cơ, đảm bảo lực đẩy mạnh nhất mà
không bị sụt áp hệ thống. - | Đường nguồn nuôi chip xử lý: Dòng điện qua một mạch hạ áp DC-Buck hạ
| xuống 5 V và 3.3 V ổn định để cấp phát cho ESP32, cảm biến ToF và siêu âm, tránh hiện tượng nhiễu xung ngược từ động cơ làm treo vi điều khiển.

12

### 3. Danh mục vật tư:

STT | ID | Linh kiện | Thông số kỹ thuật | SL | Chức năng
1 | U1 | Mạch điều khiển trung tâm ESP32-WROOM-32D | - SoC 32-bit Dual-core Xtensa LX6, 240 MHz. - Bộ nhớ: 520 KB SRAM, 4 MB Flash. - Tích hợp bộ tạo xung ledc PWM độ phân giải 8-bit. | 01 | Khối xử lý trung tâm, tiếp nhận cảm biến, thực hiện thuật toán dung hợp và quản lý máy trạng thái
2 | U4 | IC Driver động cơ TB6612FNG | - Driver cầu H hiệu suất cao - Nguồn động lực: 2.5 − 13.5 V - Nguồn logic: 2.7 − 5.5 V - Dòng điện: 1.2A/kênh - Tần số PWM: 100 kHz. | 01 | Nhận xung PWM 20 kHz và tín hiệu đảo chiều từ ESP32 để điều khiển độc lập tốc độ, hướng 2 động cơ.
3 | U3 | Cảm biến khoảng cách HC-SR04 | - Tần số định hướng: 40 kHz. - Điện áp hoạt động: 5V DC. - Góc quét: ≤ 15∘ - Dải đo: 2 − 60 cm. | 01 | Quét tìm kiếm đối thủ ở vùng biên diện rộng; phối hợp cùng ToF để xác định góc lệch trái/phải.
4 | S1 S2 | Cảm biến dò biên TCRT5000 | - Cặp LED bước sóng 950nm. - Khoảng cách phản xạ tối ưu: 2.5 − 12 mm. - Đầu ra số: HIGH / LOW | 02 | Đặt hướng xuống mặt sàn ở mép trước để phát hiện vạch biên trắng (rộng 2.5 cm) qua tín hiệu ngắt phần cứng.
5 | M1 M2 | Động cơ DC giảm tốc | - Hộp số giảm tốc tỉ lệ 1:48 - Tốc độ không tải:200 RPM. - Momen xoắn: 0.8 kg.cm. | 02 | Khối chấp hành cơ khí, biến đổi điện năng thành cơ năng sinh lực đẩy momen xoắn
6 | BAT1 | Pin lưu trữ Li-ion 18650 | - Cấu hình 2 cell mắc nối tiếp - Điện áp danh định: 7.4 V - Dòng xả tối đa: ≥ 10A. | 02 | Cung cấp nguồn năng lượng cho toàn mạch; đi dây trực tiếp tới mạch động lực Driver.
7 | U5 | Mạch hạ áp DC-DC Buck | - Điện áp vào: 4.5 − 28V, áp ra cố định: 5.0 V DC. - Dòng ra tối đa: 2A, hiệu suất chuyển đổi ≥ 90%. | 01 | Hạ áp từ nguồn pin 2S xuống 5V ổn định nuôi ESP32 và khối cảm biến; cách ly nhiễu back-EMF từ động cơ.
8 | SW1 | Nút nhấn khởi động | - Kiểu nút nhấn nhả, định mức: 50mA @ 12V DC. - Cấu hình điện trở kéo lên nội bộ. | 01 | Giao tiếp người - máy; kích hoạt chu trình FSM bắt đầu đếm ngược thời gian trễ 5 giây đầu trận.
9 W1 | W2 | Bánh xe | - Đường kính: 65 mm, chiều rộng: 26 mm. | 02 | Chuyển đổi chuyển động quay của động cơ thành

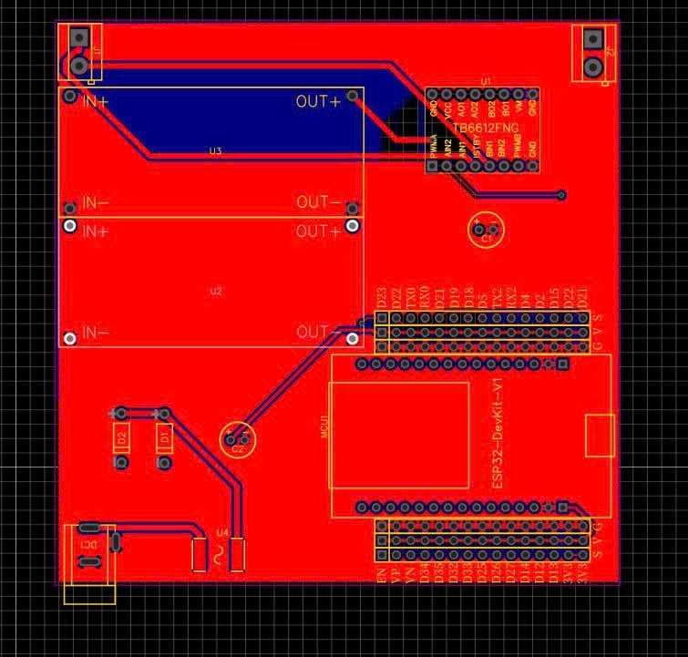
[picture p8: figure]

13

| | | - Lốp cao su lưu hóa có gai bám đường, lõi nhựa ABS. | | chuyển động tịnh tiến; tối ưu ma sát với mặt sàn gỗ MDF.
10 | PCB | Mạch in hệ thống PCB | - Vật liệu nền: Sợi thủy tinh FR4 độ dày 1.6 mm. - Độ dày lớp đồng: 1 oz (35 μm), bo mạch 2 lớp - Độ rộng đường mạch động lực cấp nguồn: ≥ 40 mil. | 01 | Tích hợp toàn bộ hệ thống đường dây kết nối, cố định các module shield, triệt tiêu dây cắm rời để tăng độ bền cơ học.
11 | T1 | Cảm biến ToF | - Công nghệ Time-of-Flight - Dải đo: 30 − 600 mm - Tốc độ lấy mẫu: 25 ms | 01 | Khóa mục tiêu chính diện, cung cấp phản hồi khoảng cách tốc độ cao

Ảnh: Bảng mạch PCB
IV. THIẾT KẾ CƠ KHÍ

### 1. Ý tưởng thiết kế cấu trúc:

- Tầng đáy: Nơi lắp đặt cặp động cơ DC giảm tốc TT bố trí đối xứng, hai bánh xe chủ động 65 mm và lưỡi ủi ở phía trước. Cặp cảm biến dò biên TCRT5000 được thiết kế gá treo hướng thẳng góc xuống mặt sàn, cách mép trước lưỡi ủi 5 mm để tối ưu tốc độ phản hồi khi chạm vạch.

14

- Tầng giữa: Khu vực bố trí khối nguồn Pin Li-ion 18650 2S. Pin được đặt nằm ngang, song song với trục bánh xe nhằm dồn trọng lượng lớn nhất vào chính giữa xe, giúp cân bằng lực tải lên cả hai bánh.
- Tầng thượng: Vị trí đặt Board mạch in hệ thống tích hợp MCU ESP32 , IC Driver TB6612FNG và module hạ áp. Cảm biến siêu âm HC-SR04 được đặt đồng trục trên một giá đỡ vát dốc góc ở mặt tiền, hướng ra phía trước để tạo thành radar kép khóa mục tiêu.
- Thiết kế lưỡi ủi chống lật
- Nguyên lý vận hành: Khi va chạm trực diện, góc vát biến lực đẩy ngang của đối thủ thành áp lực hướng xuống, ép bánh xe của robot nhóm xuống mặt sàn để tăng ma sát.
- Ràng buộc an toàn: Phần mép tiếp xúc sàn được mài tù góc, tuyệt đối không sắc bén để tuân thủ quy định an toàn của giải đấu, tránh làm xước bề mặt sàn hoặc phá hủy robot đối phương.

### 2. Phương pháp chế tạo

a. Công nghệ in 3D cho các chi tiết chịu lực phức tạp
- Vật liệu sử dụng: Nhựa PLA có độ cứng cao, co ngót nhiệt thấp, đảm bảo độ chính xác kích thước bắt vít.
- Thông số cấu hình:
Thông số | Giá trị | Mục đích
Độ dày lớp in | 0.2-0.8 mm | Đạt độ mịn bề mặt tối ưu, cân bằng giữa thời gian in và chất lượng ngoại quan.
Mật độ khối đặc | 40% | Đảm bảo độ cứng cáp cho khung vỏ mà không làm robot quá nặng, tối ưu trọng lượng.
Kiểu cấu trúc in | Gyroid | Cấu trúc tối ưu nhất trong cơ học: Giúp hấp thụ và phân tán xung lực đồng đều mọi hướng, chống nứt vỡ khi va chạm mạnh

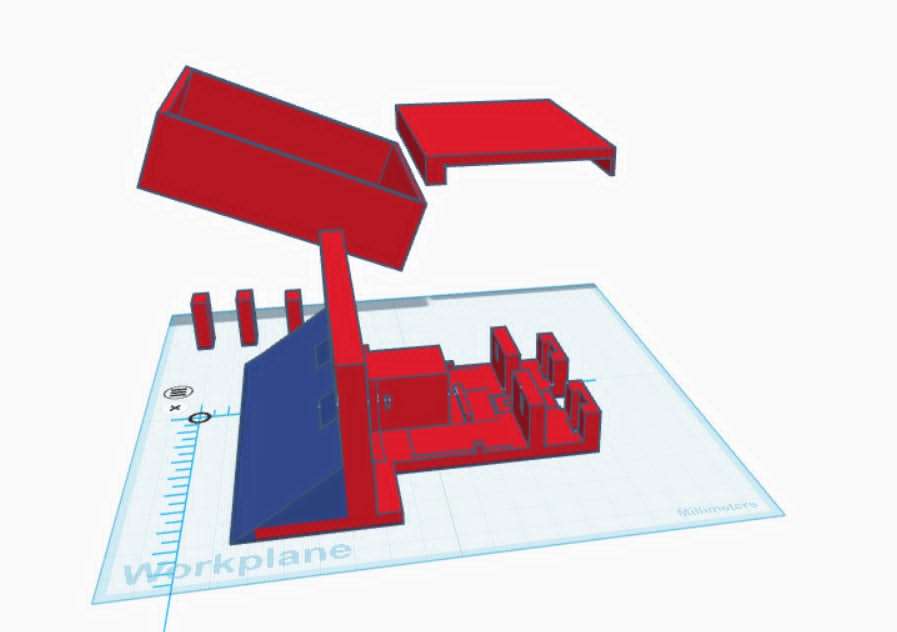
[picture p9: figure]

15

Ảnh: Bảng mẫu In 3D
b. Tính toán cơ lý học hệ thống
- Bài toán tối ưu hóa và hạ thấp vị trí trọng tâm
Vị trí trọng tâm quyết định độ ổn định chống lật của robot. Nếu trọng tâm quá cao hoặc lệch về phía sau, khi tăng tốc dồn ép đối thủ, mô-men lực ngược chiều sẽ làm nhấc bổng lưỡi ủi lên, khiến robot mất khả năng bám sàn.
Nhóm tiến hành phân bổ tọa độ các linh kiện nặng nhất theo phương đứng :
- Hai động cơ TT và khối pin Li-ion 2S được đặt áp sát mặt sàn Mica
- Mạch PCB và ESP32 nhẹ hơn được đưa lên tầng trên
Nhờ phân bổ vật liệu thông minh, trọng tâm tổng thể G của robot được hạ xuống sát đáy. Điều này đảm bảo khi có ngoại lực đẩy từ đối thủ tác động vào lưỡi ủi, vector lực luôn đi qua hoặc nằm dưới trọng tâm, triệt tiêu mô-men gây lật xe.
- Tính toán lực bám ma sát lý thuyết

16

Theo định luật Columb:

F ≤ F = μ ⋅ N
Trong đó:
μ: Hệ số ma sát giữa lốp cao su lưu hóa và mặt sân

N: Phản lực từ mặt sàn tác dụng lên các bánh xe chủ động. Khi robot đứng cân bằng trên mặt phẳng ngang
Áp dụng số liệu tổng khối lượng ước tính của robot sau khi tối ưu hóa cấu trúc cơ khí là m = 600g, với gia tốc trọng trường g ≈ 9.81 m/s
:

F = 0.85 ⋅ 0.600 ⋅ 9.81 ≈ 5 N
V. PHẦN MỀM & FIRMWARE ĐIỀU KHIỂN

### 1. Trạng thái vận hành

Hệ thống FSM của robot được chia thành 6 trạng thái chiến thuật chính (MatchState), bao phủ toàn bộ vòng đời của một hiệp đấu Sumo:
- WAIT_START: Trạng thái chờ tín hiệu. Robot vô hiệu hóa động cơ, chờ người dùng nhấn nút START (có chống rung phím - debounce 35ms) để bắt đầu.
- PHASE_1_PROBING: Khởi động 5 giây theo luật thi đấu quốc tế. Trong thời gian này, robot đứng im nhưng liên tục "lắng nghe" và thu thập dữ liệu khoảng cách từ cả cảm biến siêu âm và ToF để phân tích vị trí ban đầu của đối thủ.
- PHASE_2_JUKE & PHASE_2_BRAKE: Chiến thuật né tránh (Juke) đầu trận. Kết thúc 5 giây, robot sẽ xoay gấp (pivot) để thoát khỏi đường ngắm của đối thủ nếu đối phương lao thẳng, sau đó phanh điện từ (shortBrakeMotor) triệt tiêu quán tính.
- PHASE_3_RELOCK: Tìm kiếm và khóa mục tiêu. Robot quét góc để tìm lại đối thủ dựa trên hướng né tránh trước đó. Khi cảm biến xác nhận mục tiêu ổn định (TARGET_ACQUIRE_COUNT), hệ thống chuyển sang tấn công.
- PHASE_4_STRIKE: Chuỗi hành động tấn công. Bao gồm 3 pha phụ (Sub-states):
o Approach: Tiếp cận với tốc độ vừa phải.
o Contact Test: Kiểm tra va chạm khi đến gần.

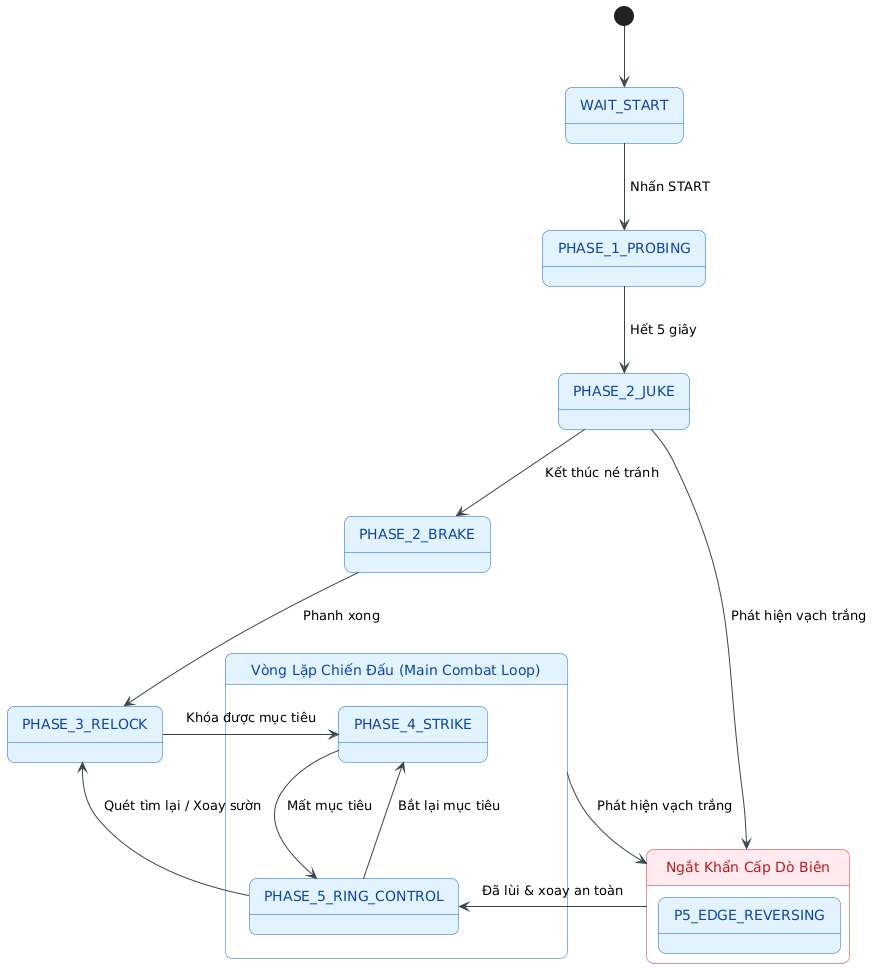
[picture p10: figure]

17

o Attack Burst: Bơm tối đa công suất khi xác nhận đã khóa chặt đối thủ.
- PHASE_5_RING_CONTROL: Kiểm soát sàn đấu. Xử lý các tình huống phức tạp như: bị kẹt (Anchor Escape), móc sườn (Flank Arc), mất mục tiêu (Blind Rush) và đặc biệt là xử lý thoát vạch trắng cứu nguy.

### 2. Lưu đồ thuật toán máy trạng thái tổng thể

### 3. Phân tích giải thuật dung hợp cảm biến

Robot không tin tưởng mù quáng vào một cảm biến duy nhất mà sử dụng kỹ thuật dung hợp (Sensor Fusion) giữa ToF VL53L0X (đo bằng laser) và HC-SR04 (siêu âm). Giải thuật này diễn ra mạnh mẽ nhất ở finalizePhase1():
- Đánh giá độ tin cậy: Do ToF có chùm tia hẹp và chính xác hơn, nó được gán trọng số cao hơn (55%) so với siêu âm (45%). Độ tin cậy tổng hợp được tính toán theo công thức:

18

C = 0.55 × R + 0.45 × R

(Trong đó R là tỷ lệ thu được mẫu dữ liệu hợp lệ trên tổng số lần ping).
- Bộ lọc trung vị: Dữ liệu khoảng cách thu về được đẩy vào hai mảng usSamples và tofSamples. Thay vì tính trung bình cộng (dễ bị sai lệch bởi một giá trị nhiễu đột biến), thuật toán sắp xếp mảng (Insertion Sort) và lấy giá trị đứng ở giữa (Median). Điều này loại bỏ hoàn toàn các điểm mù (Outliers) do nhiễu sóng hoặc bề mặt phản xạ kém.
- Chống Jitter (Nhiễu thời gian): Thời gian lấy mẫu siêu âm không cố định mà dao động ngẫu nhiên (ví dụ: US_PROBE_MIN_INTERVAL_MS đến US_PROBE_MAX_INTERVAL_MS). Việc tạo ra khoảng Jitter này giúp robot tránh bị cộng hưởng nhiễu sóng với cảm biến siêu âm của robot đối thủ trên cùng sàn đấu.

### 4. Cơ chế ngắt dò biên và gia tốc mềm thực chiến

a. Ngắt cứu nguy khẩn cấp
Thay vì sử dụng ngắt phần cứng có thể gây xung đột bộ nhớ và trên ESP32 khi gọi các hàm điều khiển động cơ, firmware sử dụng cơ chế hỏi vòng ưu tiên cao
Trong mọi trạng thái chiến đấu (Phase 2, 3, 4, 5), câu lệnh if (edgeDetected()) luôn được đặt ở dòng đầu tiên của vòng lặp xử lý. Khi phát hiện mức logic cảnh báo (vạch trắng), robot lập tức:
1. Bỏ qua mọi chu trình tấn công hoặc tìm kiếm hiện tại.

### 2. Chuyển cưỡng chế trạng thái về PHASE_5_RING_CONTROL với Sub-state là

P5_EDGE_REVERSING.

### 3. Thực hiện chuỗi thoát hiểm: Phanh gấp → Lùi lại một khoảng thời gian cực

ngắn → Xoay người để đưa cảm biến trở lại vùng an toàn (sàn đen).
b. Kỹ thuật điều khiển gia tốc mềm
Động cơ không bao giờ bị sốc điện bằng cách nhảy vọt từ 0 lên 100% công suất, điều này gây trượt bánh (mất ma sát tĩnh) và sụt áp pin đột ngột. Mã nguồn áp dụng kỹ thuật gia tốc theo từng bậc chiến thuật (Tactical Staged PWM):
- Tìm kiếm (PWM_SEARCH - 90): Xoay chậm rãi để các cảm biến có đủ thời gian bắt hình ảnh, không bị bỏ lọt mục tiêu do tốc độ quét quá cao.

19

- Tiếp cận (PWM_APPROACH - 175): Tốc độ trung bình nhanh để rút ngắn khoảng cách nhưng vẫn chừa lại độ bám đường.
- Thử va chạm (PWM_CONTACT_TEST - 190): Tăng nhẹ lực đẩy khi cách đối thủ một khoảng ngắn (14cm) để tạo đà.
- Bùng nổ (PWM_ATTACK_BURST - 205): Khi xác nhận đã chạm dính đối thủ, bơm dòng tối đa để đẩy đối phương ra khỏi đài.
- Phanh điện từ: Sử dụng tính năng IN1 = IN2 = HIGH của IC TB6612. Mạch sẽ nối tắt cuộn dây động cơ, tạo ra lực từ trường ghì chặt rotor lại ngay lập tức thay vì để robot trôi theo quán tính.
VI. TRIỂN KHAI & TÍCH HỢP HỆ THỐNG

### 1. Quy trình lắp ráp hệ thống

Bước | Nhiệm vụ | Nội dung | Tiêu chuẩn (QC)
1 | Cơ khí đáy | - Gá đặt cặp động cơ DC TT vào tấm nền. - Ép trùng khít trục vát bánh xe cao su. | - Độ rơ lắc cơ khí trục động cơ:0 mm. - Kiểm tra khuôn vuông
2 | Điện & Nguồn | - Cố định khối pin Li-ion 18650 2S vào buồng bảo vệ cách điện. - Bắt vít bo mạch in PCB lên cọc đồng | - Cách ly tuyệt đối vỏ pin với các cạnh sắc mechanical. - Đo kiểm tra ngắn mạch
3 | Cảm biến | - Định vị radar kép trên giá đỡ vát dốc mặt tiền. - Treo TCRT5000 hướng vuông góc xuống mặt sân. | - Khoảng cách từ mắt phát/thu TCRT5000 tới mặt sàn: Cố định 5 mm. - Trục cảm biến ToF và siêu âm song song tuyệt đối.
4 | Tín hiệu | - Đi dây bus tín hiệu từ cảm biến trên PCB. | - Triệt tiêu hiện tượng chồng chéo dây gần cuộn dây động cơ để chống nhiễu cảm ứng điện từ

20

- Sử dụng kỹ thuật xoắn
đôi cho các đường dây
analog/I2C.

### 2. Lịch sử tiến hóa

- Phiên bản 1.0:
Đặc điểm: Thử nghiệm tính đúng đắn của giải thuật điều khiển FSM
Hạn chế: Dây cắm lỏng lẻo, điện trở tiếp xúc cao dẫn đến sai số tín hiệu. Hệ thống bị treo liên tục khi robot thực hiện các chuyển động rung lắc mạnh.
- Phiên bản 2.0:
Đặc điểm: Linh kiện được cố định trên mạch.
Hạn chế: Việc sử dụng IC điều khiển L298N công nghệ BJT gây tổn hao nhiệt lớn và làm sụt áp nghiêm trọng trên tầng công suất, khiến động cơ không đạt được momen xoắn cực đại. Trọng tâm xe còn cao, dễ bị đối thủ lật nhào khi va chạm chéo góc.
- Phiên bản 3.0:
Đặc điểm: Cấu trúc cơ khí ứng dụng công nghệ in 3D
Kết quả: Robot đạt độ bền cơ - điện tuyệt đối, tối ưu hóa 100% công suất nguồn pin pin 2S, thỏa mãn xuất sắc mọi ràng buộc về khối lượng và kích thước.

### 3. Một số vấn đề tồn đọng:

- Gai nhiễu sụt áp nguồn lực kích hoạt bảo vệ

Hiện tượng lâm sàng: Khi robot đang di chuyển bình thường, ngay tại thời điểm thuật toán ra lệnh đảo chiều động cơ đột ngột hoặc khi lưỡi ủi va chạm mạnh trực diện vào đối thủ, chip xử lý trung tâm ESP32 lập tức bị đóng băng (treo) hoặc tự động reboot (khởi động lại) ngẫu nhiên.
Phân tích kỹ thuật: Động cơ DC giảm tốc chổi than khi khởi động hoặc khi bị kẹt dòng sẽ rút một dòng điện đỉnh vượt ngưỡng 3 A. Dòng điện xả tức thời này gây ra hiện tượng sụt áp cục bộ trên đường nguồn chung của pin Li-ion 2S. Điện áp cấp phát cho ESP32 sụt xuống dưới 3.0 V, kích hoạt tính năng an toàn ngắt mạch khi sụt áp tích hợp trong cấu trúc của vi điều khiển.

21

Giải pháp khắc phục: Tiến hành sửa đổi sơ đồ Schematic, cô lập hoàn toàn hai đường nguồn
- Nhiễu giao thoa chéo tần số sóng âm khi đấu đối kháng

Hiện tượng lâm sàng: Khi vận hành đơn lẻ trên sa bàn thử nghiệm, cảm biến siêu âm HC-SR04 đo đạc khoảng cách mục tiêu rất ổn định. Tuy nhiên, khi đưa vào trận đấu đối kháng thực tế với robot của đội bạn, cảm biến liên tục trả về dữ liệu ảo dao động liên tục từ 2 cm − 4 cm, khiến FSM ngộ nhận đối thủ đã áp sát và phát lệnh tấn công sai thời điểm.
Phân tích kỹ thuật: Robot đối phương cũng sử dụng cảm biến siêu âm hoạt động ở tần số nền tiêu chuẩn 40 kHz. Chùm sóng âm phát ra từ robot đối phương đã truyền trực tiếp vào đầu thu của robot nhóm. Vi điều khiển ESP32 bắt nhầm sườn xung phản hồi của đối thủ, dẫn đến việc tính toán sai lệch hoàn toàn thời gian bay của sóng âm
Giải pháp khắc phục: Tối ưu hóa cấu trúc firmware phần mềm. Hệ thống chuyển đổi logic tìm kiếm: thay vì phát xung phát liên tục, robot thực hiện chu kỳ nhích xoay tại chỗ trong thời gian 150 ms, sau đó ra lệnh ngắt dòng động cơ khựng lại trong 50 ms liên tục. Hàm lấy mẫu siêu âm chỉ được kích hoạt duy nhất trong thời điểm 50 ms đứng yên này, phối hợp bộ lọc trung vị lấy 3 mẫu liên tiếp để làm sạch dữ liệu đầu vào
- Sai số đáp ứng động học và quán tính phanh vượt vạch biên

Hiện tượng lâm sàng: Khi robot di chuyển tìm kiếm hoặc tấn công với tốc độ cao, dù mắt hồng ngoại TCRT5000 đã nhận diện chính xác vạch trắng ranh giới, robot vẫn bị trượt theo quán tính lao thẳng ra ngoài vòng tròn thi đấu. Phân tích kỹ thuật : Thuật toán cũ áp dụng cơ chế đọc dữ liệu cảm biến tuần tự đặt trong hàm loop() chính. Khi ESP32 đang phải thực thi tác vụ tính toán dung hợp dữ liệu radar hoặc đang đợi lệnh phản hồi từ hàm đo khoảng cách, nó sẽ tạo ra một độ trễ vòng lặp. Ở vận tốc tối đa, trong khoảng thời gian trễ này, robot đã kịp di chuyển thêm một quãng đường 5 − 8 cm, vượt xa độ rộng
2.5 cm của vạch biên trắng.
Giải pháp khắc phục: Tái cấu trúc phân bổ chân tín hiệu ngoại vi và phần mềm

22

VII. KIỂM THỬ HỆ THỐNG

### 1. Kiểm thử và đánh giá tính năng

ID | Quy trình thực hiện | Kết quả kỳ vọng | Trạng thái
TC-01 | Chức năng: Kiểm tra hệ thống cấp nguồn và khởi tạo hệ thống . Dịch chuyển: FAULT → IDLE_WAIT_BUTTON. Quy trình: Bật công tắc nguồn từ pin Li-ion 2S. Hệ thống tự động kiểm tra driver PWM và cảm biến ToF VL53L0X. | Nếu phần cứng sẵn sàng, robot dừng động cơ và chuyển sang chế độ chờ. Nếu lỗi, khóa trạng thái FAULT. | Đạt
TC-02 | Chức năng: Kiểm tra nút nhấn và thời gian trễ Dịch chuyển: IDLE_WAIT_BUTTON → COUNTDOWN_5S. Quy trình: Đặt robot sau vạch xuất phát, nhấn nút Start. Đo thời gian đứng yên của robot. | Robot phải đứng yên hoàn toàn trong đúng 5 giây. Không được phép dịch chuyển trước thời gian này. | Đạt
TC-03 | Chức năng: Kiểm tra chiến thuật né đầu trận Dịch chuyển: COUNTDOWN_5S → MATADOR_DODGE . Quy trình: Ngay sau khi hết 5 giây đếm ngược, quan sát quỹ đạo di chuyển của robot trong chớp nhoáng. | Robot thực hiện cú bẻ lái vòng cung nhanh sang phải trong đúng 350 ms để né đòn húc thẳng. | Đạt
TC-04 | Chức năng: Kiểm tra cơ chế ngắt an toàn Dịch chuyển: Duy trì trạng thái MATADOR_DODGE . Quy trình: Kích hoạt cảm biến biên vạch trắng bằng cách đặt giấy trắng dưới gầm ngay trong 350 ms đầu hiệp. | Biến cờ ngắt bị bỏ qua. Robot không tự hủy để đảm bảo thực thi xong cú lách né. | Không đạt

23

TC-05 | Chức năng: Kiểm tra cơ chế tìm chống nhiễu. Dịch chuyển: MATADOR_DODGE → SEARCH_SCAN . Quy trình: Sau khi kết thúc đòn nhử 350 ms, robot chuyển sang quét tìm kiếm đối thủ khi chưa có vật cản. | Robot xoay quét theo cơ chế Jitter Scan: Nhích xoay 150 ms rồi dừng khựng lại đột ngột 50 ms để triệt tiêu nhiễu sóng. | Đạt
TC-06 | Chức năng: Kiểm tra rà góc chính xác khi phát hiện mục tiêu biên . Dịch chuyển: SEARCH_SCAN → TRACKING . Quy trình: Đặt một vật cản ở góc rộng trong phạm vi ≤ 60 cm để cảm biến siêu âm bắt được nhưng tia laser ToF quét trượt. | Robot lập tức chuyển sang TRACKING, giảm tốc độ xoay xuống mức rất chậm (xung 100) để triệt tiêu quán tính cơ khí. | Đạt
TC-07 | Chức năng: Kiểm tra gia tốc mềm kiểm soát lực bám khi tấn công . Dịch chuyển: TRACKING/SEARCH_SCAN → ATTACK . Quy trình: Đưa vật cản vào chính diện đầu xe trong phạm vi khóa mục tiêu của tia laser ToF (≤ 600 mm). | Robot khóa mục tiêu (TARGET_LOCKED), kích hoạt Traction Control bơm mềm xung PWM từ 150 lên 255 trong 100 ms đầu để chống trượt bánh trước khi húc max ga. | Đạt
TC-08 | Chức năng: Kiểm tra khả năng chống mất dấu mục tiêu. Dịch chuyển: Duy trì trạng thái ATTACK . Quy trình: Khi đang húc ở trạng thái tấn công, đột ngột rút vật cản ra ngoài trong khoảng thời gian cực ngắn (< 200 ms). | Robot vẫn giữ nguyên trạng thái lao lên tấn công, không bị khựng lại hay đổi hướng đột ngột do mất dấu chớp nhoáng. | Đạt
TC-09 | Chức năng: Kiểm tra ngắt phần cứng khẩn cấp khi chạm vạch biên . Dịch chuyển: ATTACK/SEARCH_SCAN → LINE_REVERSE . | Mạch ngắt onLineDetected bắt sườn xuống lập tức. Robot dừng mọi tác vụ, lùi toàn | Đạt

24

| Quy trình: Cho robot đang di chuyển (tìm kiếm hoặc tấn công), dùng giấy trắng kích hoạt đột ngột cảm biến biên PIN_LINE. | lực (-255, -255) về vùng an toàn.
TC-10 | Chức năng: Kiểm tra logic thoát hiểm quay đầu khi gặp vạch biên . Dịch chuyển: LINE_REVERSE → LINE_TURN → SEARCH_SCAN . Quy trình: Quan sát hành vi của robot sau khi thực hiện xong chu trình lùi khẩn cấp qua vạch biên. | Robot tự động đổi hướng quay nhanh (200, -200 hoặc ngược lại) trong đúng 300 ms để hướng xe ra khỏi vạch trắng trước khi tìm kiếm lại. | Không đạt

### 2. Số liệu đo đạc kỹ thuật và đánh giá hiệu năng thực tế

a. Đánh giá đáp ứng khoảng cách của hệ thống
Thực tế | HC-SR04 (cm) | Sai số | ToF VL53L0X (cm) | Sai số | Đánh giá
5 | 5.2 | 4.00% | 5.1 | 2.0% | Vùng khóa mục tiêu chính diện an toàn
15 | 15.28 | 1,87% | 15.2 | 1.3% | Cả 2 cảm biến trùng khớp
30 | 29,53 | 1,57% | 30.3 | 1.0% | ToF Laser giữ độ ổn tốt
b. Đo đạc động học và năng lực cơ lý thực chiến
Tham số | Giá trị trung bình | Phương pháp | Đánh giá
Khối lượng | 645 g | Cân điện tử | Đạt tiêu chuẩn
Vận tốc tuyến tính (v) | 0.62 m/s | Chạy toàn tải trên bề mặt lòng sân sơn đen nhám | Đảm bảo tốc độ áp sát
Thời gian phanh dừng chạm vạch | 45 ms | Tính từ lúc mắt TCRT5000 đè vạch trắng đến khi robot lùi lại | Nhờ ngắt phần cứng, robot không bị trượt quá vạch biên
Thời gian trễ | 5.02 s | Bấm giờ điện tử từ lúc nhấn nút đến khi bánh xe quay | Hoàn toàn hợp lệ

VIII.CHIẾN THUẬT THI ĐẤU & ĐỐI SÁCH THỰC CHIẾN

### 1. Phân tích đặc tính hệ thống

25

- Điểm mạnh:
- Trọng tâm thấp giúp chống lật khi va chạm.
- Hệ thống phản xạ ngắt biên bằng phần cứng nhạy, triệt tiêu độ trễ vòng lặp.
- Thuật toán gia tốc mềm cho lực đẩy tĩnh tối đa mà không lo trượt bánh.
- Tích hợp radar kép phối hợp bộ lọc trung vị giúp chống nhiễu sóng âm chéo từ robot đối phương cực tốt.
- Điểm yếu:
- Vận tốc tuyến tính ở mức trung bình do giới hạn tỷ số truyền của động cơ
- Góc quét của tia Laser ToF khá hẹp; nếu đối thủ lách qua vùng biên quá nhanh, robot sẽ mất thêm chu kỳ xoay để tìm lại mục tiêu.
- Cơ hội:
- Tận dụng luật trễ 5 giây: Luật quy định mọi robot phải đứng yên đúng 5 giây sau khi nhấn nút khởi động. Việc cấu hình bộ đếm thời gian chính xác trên ESP32 giúp nhóm tránh hoàn toàn nguy cơ bị xử thua do di chuyển sớm, đồng thời khai thác được khoảnh khắc đối thủ khởi động lỗi.
- Sai lầm tự sát của đối thủ: Thể thức loại trực tiếp khiến nhiều đội lập trình đọc cảm biến tuần tự dễ bị trượt quá vạch trắng khi di chuyển nhanh. Cơ chế thủ vững và rà góc biên của nhóm sẽ ép đối thủ tự đẩy mình ra ngoài sa bàn.
- Thách thức:
- Sơ đồ knockout khắc nghiệt: Đấu loại trực tiếp không có cơ hội sửa sai ở nhánh thua. Chỉ cần một tình huống kẹt cơ khí hoặc mất nguồn đột ngột là nhóm sẽ bị loại ngay lập tức.
- Nhiễu ánh sáng môi trường: Cảm biến dò biên TCRT5000 và cảm biến ToF Laser VL53L0X hoạt động dựa trên nguyên lý quang học. Nếu ánh sáng tại hội trường thi đấu quá mạnh hoặc thay đổi đột ngột, hệ thống có thể bị ngộ nhận vạch biên hoặc mất dấu mục tiêu chớp nhoáng.

### 2. Kịch bản chiến thuật đối phó các hệ thống Robot khác nhau

- Đối đầu với Robot nặng, lực húc thẳng mạnh, lưỡi ủi to : Phát huy tối đa trạng thái STATE_TACTICAL_DASH. Ngay khi hết 5 giây đếm ngược, thay vì lao thẳng để đấu lực trực diện, robot của nhóm sẽ thực hiện cú bẻ lái

26

vòng cung chớp nhoáng sang phải trong 350 ms. Cú lách này sẽ tận dụng quán tính lao thẳng của đối phương để né đòn, đồng thời đưa robot của nhóm vào vị trí sườn hoặc sau lưng đối thủ để thực hiện cú đẩy ép từ góc chết.
- Đối đầu với robot chạy nhanh, chiến thuật lách né, thân vỏ nhẹ Tận dụng cơ chế quét chống nhiễu phối hợp hạ tốc độ rà góc. Do đối thủ di chuyển nhanh và liên tục thay đổi vị trí, robot nhóm sẽ giữ vị trí ở vùng trung tâm sa bàn, xoay nhích ngắt quãng. Khi cảm biến siêu âm phát hiện vật thể ở góc rộng, robot lập tức giảm tốc độ xoay xuống mức xung PWM = 100 để triệt tiêu quán tính cơ học, cho phép tia laser ToF khóa đối thủ vào chính diện. Khi đối thủ đã bị khóa, thuật toán gia tốc mềm sẽ bơm xung tuyến tính lên 255 để dồn toàn lực ép đối thủ ra biên mà không sợ bị trượt bánh.
- Đối đầu với Robot sử dụng cảm biến siêu âm gây nhiễu chéo: Kích hoạt bộ lọc trung vị lấy 3 mẫu liên tiếp phối hợp ngắt động cơ khựng lại trong 50 ms của chu kỳ Jitter Scan để lấy mẫu trong môi trường tĩnh cơ học. Hệ thống sẽ cô lập dữ liệu nhiễu và chỉ tin tưởng tuyệt đối vào tín hiệu khóa từ cảm biến quang học ToF Laser VL53L0X để phát lệnh tấn công.
IX. KẾT LUẬN & HƯỚNG PHÁT TRIỂN DỰ ÁN

### 1. Các kết quả đã đạt được

- Về cơ khí: Thiết kế thành công cấu trúc khung vỏ tối ưu hóa tọa độ trọng tâm theo phương đứng bằng công nghệ in 3D kết hợp cắt laser, đảm bảo robot hấp thụ xung lực va chạm tốt và tuân thủ nghiêm ngặt các ràng buộc kích thước và khối lượng
- Về phần cứng: Chế tạo thành công bo mạch in PCB hệ thống tích hợp vi điều khiển ESP32, IC Driver TB6612FNG và các module cảm biến. Thiết kế mạch nguồn an toàn sử dụng 2 cell pin Li-ion 18650 nối tiếp có mạch hạ áp cách ly đường nguồn logic và động lực, giải quyết triệt để lỗi sụt áp sập nguồn
- Về phần mềm: Xây dựng mô hình máy trạng thái (FSM) 6 trạng thái hoạt động tuần hoàn, logic dung hợp radar kép (Siêu âm + ToF) chính xác và giải thuật ngắt cứu nguy khẩn cấp sườn xuống đạt thời gian đáp ứng
- Kỹ năng mềm: Nhóm đã làm chủ quy trình quản lý mã nguồn, phân chia nhánh phối hợp và quản lý chuyên nghiệp thông qua nền tảng GitHub.

27

### 2. Định hướng cải tiến và hướng phát triển tương lai

Mặc dù robot đã đạt trạng thái hoạt động tối ưu theo thiết kế, song do giới hạn về thời gian và kinh nghiệm, hệ thống vẫn có thể cải tiến sâu hơn ở các phiên bản tiếp theo:
- Nâng cấp động lực: Thay thế cặp động cơ DC chổi than TT bằng động cơ DC dòng cao kết hợp Encoder phản hồi vòng lặp kín để kiểm soát chính xác vận tốc thực của bánh xe, tăng tốc độ tuyến tính lên > 1.2 m/s và tăng mô-men xoắn chủ động.
- Tối ưu hóa lưỡi ủi cơ khí: Chế tạo cơ cấu lưỡi ủi bằng vật liệu hợp kim nhôm mỏng cắt CNC hoặc thép không gỉ thay vì nhựa in 3D để tăng độ sắc sảo ở mép xúc sa bàn, giúp dễ dàng luồn dưới gầm và nhấc bổng robot đối phương.
- Dung hợp cảm biến thông minh: Tích hợp thêm cảm biến gia tốc/góc quay IMU (ví dụ: MPU6050) để nhận biết trạng thái robot có đang bị đối thủ đẩy lùi hoặc bị nghiêng/nhấc bánh hay không, từ đó FSM có thể tự động đưa ra các phản xạ bẻ lái khẩn cấp để thoát hiểm thay vì chỉ phụ thuộc vào cảm biến biên.

### 3. Bảng đóng góp thành viên

Thành viên | MSSV | Nhiệm vụ | Mức độ đóng góp
Hoàng Việt Anh | 25112007 | - Theo dõi, quản lí tiến độ - Lắp ráp linh kiện,đặt bảng in PCB và các công việc phần cứng - Tối ưu hóa mã nguồn, tiến hành gỡ lỗi và kiểm thử thực tế. | 30%
Lê Văn Thái An | 25112001 | - Khảo sát yêu cầu đề bài - Mua và hỗ trợ lắp ráp phần cứng - Lên ý tưởng và lập thuật toán - Hỗ trợ lắp ráp sản phẩm - Viết báo cáo dự án | 28%
Dương Hoàng An | 25112002 | - Hỗ trợ gia công cơ khí - Tổng hợp và hỗ trợ viết báo cáo - Tiến hành hiệu chuẩn thiết bị - Đồng nghiên cứu phần mềm | 28%
Lê Văn Trường | 25119064 | - Tham gia vẽ bản thiết kế 3D cho robot (tuy nhiên bản vẽ gặp lỗi về kích thước). | 14%

28

- Ít tham gia hỗ trợ nhóm trong các công đoạn khác của dự án.
X. TÀI LIỆU THAM KHẢO & PHỤ LỤC

### 1. Tài liệu tham khảo

### 1. TS. Bùi Huy Kiên, MSc. Nguyễn Tiến Đạt, Hướng dẫn sinh viên & Thể lệ học

phần AET2021: Thí nghiệm trong Khoa học và Kỹ thuật 1, Trường Đại học Việt Nhật, ĐHQGHN, 2021.
2. Espressif Systems, ESP32 Technical Reference Manual, v4.6, 2023.
3. Toshiba Semiconductor, TB6612FNG Driver Datasheet, 2014.
4. STMicroelectronics, VL53L0X Time-of-Flight Distance Sensor Datasheet, 2016.

### 2. Phụ lục dự án

- Đường dẫn Repository GitHub chính thức của dự án: https://github.com/WataruAki/SumoRobot
- Cấu trúc tổ chức thư mục trên GitHub của nhóm:
o /firmware: Chứa toàn bộ mã nguồn C/C++ lập trình trên Framework Arduino/ESP-IDF cho ESP32.
o /hardware: Bản vẽ nguyên lý Schematic, Layout bo mạch PCB 2 lớp bằng Altium Designer/EasyEDA.
o /mechanical: File thiết kế 3D CAD (.STEP), file xuất in 3D (.STL) của khung xe và gá cảm biến, file dxf cắt laser lưỡi ủi.
o /docs: Chứa file báo cáo kỹ thuật hoàn chỉnh, tài liệu hướng dẫn vận hành và các biểu đồ đo đạc.
o README.md: Mô tả tổng quan dự án, danh sách thành viên và bảng phân công công việc chi tiết.

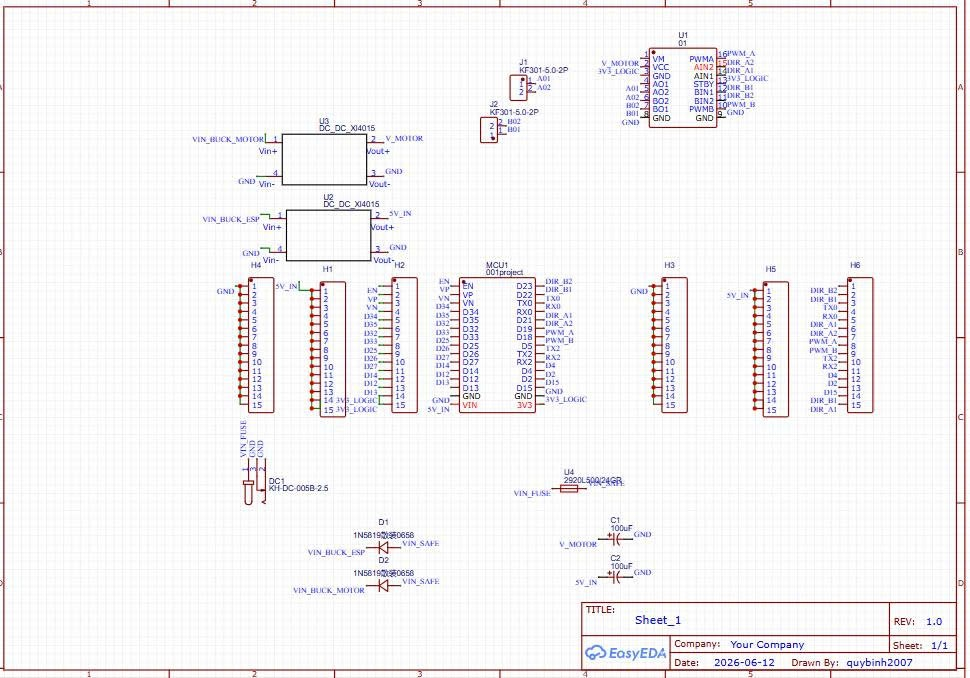
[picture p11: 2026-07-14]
hardware/Schematic.png

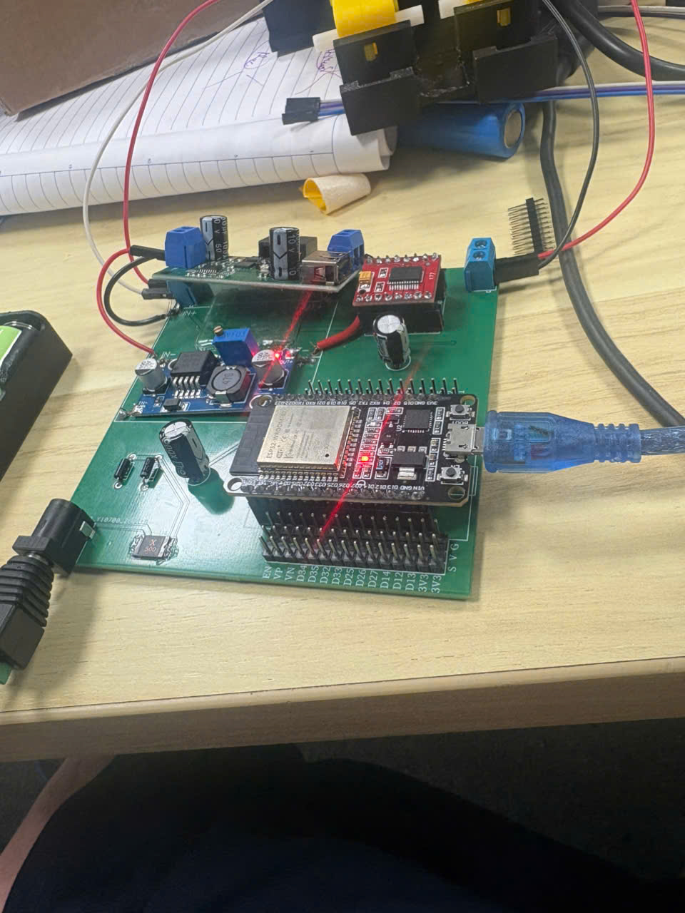
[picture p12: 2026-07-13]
docs/Minh hoa/A2.jpg

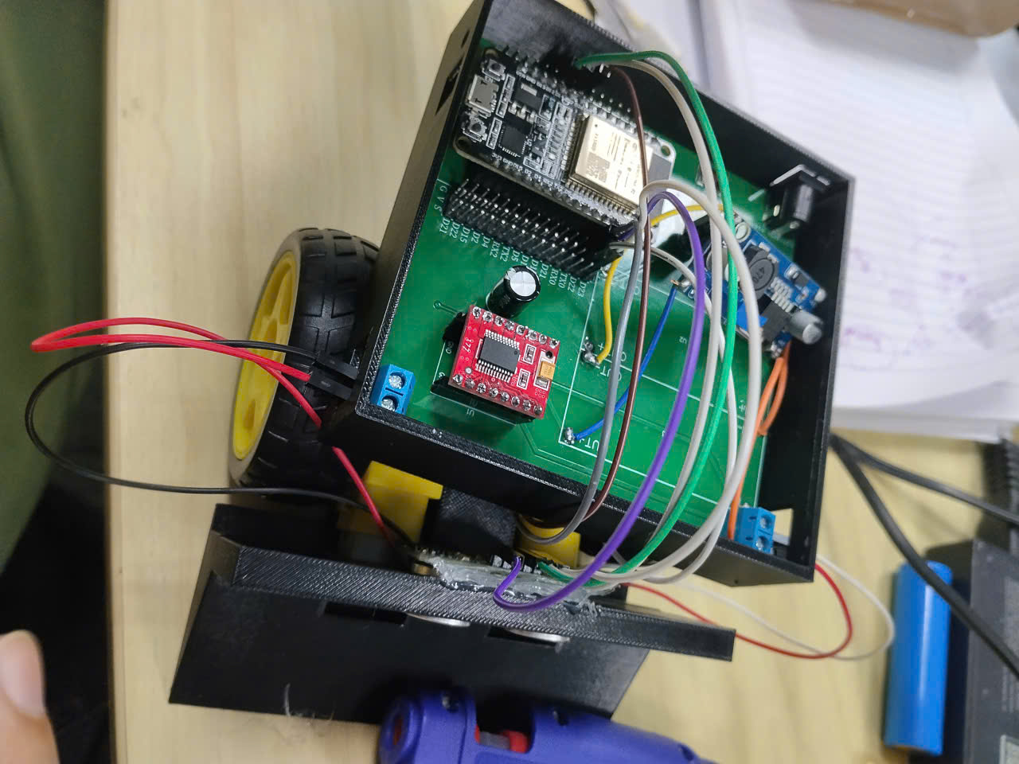
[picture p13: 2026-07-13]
docs/Minh hoa/A1.jpg

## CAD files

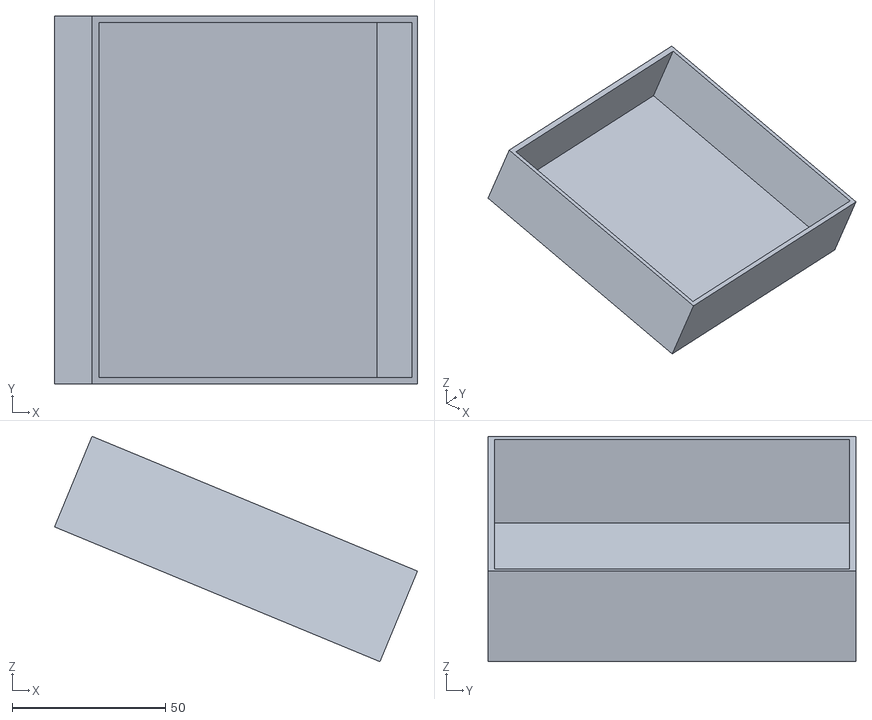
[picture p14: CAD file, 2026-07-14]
mechanical/Case.stl
118.5 x 120.0 x 73.6

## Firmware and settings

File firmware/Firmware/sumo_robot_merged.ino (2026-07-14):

#include <Arduino.h>
#include <esp_system.h>

#if __has_include(<esp_arduino_version.h>)
#include <esp_arduino_version.h>
#endif

#ifndef ESP_ARDUINO_VERSION_MAJOR
#define ESP_ARDUINO_VERSION_MAJOR 2
#endif

// ================================================================
// CAU HINH PHAN CUNG - SUA CAC CHAN THEO MACH THUC TE
// Ho tro API LEDC cua ca Arduino-ESP32 Core 2.x va 3.x.
// ================================================================

// Phan bo chan tranh trung voi TB6612 va tranh I2C mac dinh 21/22.
constexpr uint8_t PIN_START_BUTTON = 27;  // Nut noi xuong GND

constexpr uint8_t PIN_US_TRIG = 25;
constexpr uint8_t PIN_US_ECHO = 26;       // HC-SR04 ECHO phai ha 5 V xuong 3.3 V

constexpr uint8_t PIN_TOF_SDA = 33;
constexpr uint8_t PIN_TOF_SCL = 13;

// TB6612 theo danh sach chan day thuc te:
// Kenh A = motor trai, kenh B = motor phai.
constexpr uint8_t PIN_LEFT_PWM  = 18;  // PWMA
constexpr uint8_t PIN_LEFT_IN1  = 21;  // AIN1
constexpr uint8_t PIN_LEFT_IN2  = 19;  // AIN2
constexpr uint8_t PIN_RIGHT_PWM = 5;   // PWMB
constexpr uint8_t PIN_RIGHT_IN1 = 22;  // BIN1
constexpr uint8_t PIN_RIGHT_IN2 = 23;  // BIN2

// Doi false -> true neu mot ben quay nguoc khi ra lenh tien.
constexpr bool INVERT_LEFT_MOTOR = false;
constexpr bool INVERT_RIGHT_MOTOR = false;

// Mot cam bien bien dat o GIUA PHIA TRUOC, sat mat san.
// Voi chi mot cam bien, khong duoc lui lau vi phia sau khong duoc quan sat.
constexpr uint8_t PIN_EDGE_CENTER = 32;
constexpr uint8_t EDGE_WHITE_LEVEL = HIGH;  // Doi thanh LOW neu module xuat LOW tren vach trang

constexpr uint32_t PWM_FREQUENCY = 20000;
constexpr uint8_t PWM_RESOLUTION = 8;
constexpr uint8_t PWM_CHANNEL_LEFT = 0;   // Chi dung voi Arduino-ESP32 Core 2.x
constexpr uint8_t PWM_CHANNEL_RIGHT = 1;  // Chi dung voi Arduino-ESP32 Core 2.x

// Bat khi da cai thu vien Pololu VL53L0X va noi cam bien dung.
// Co the dat -DUSE_VL53L0X=1 trong build flags ma khong can sua file.
#ifndef USE_VL53L0X
#define USE_VL53L0X 0
#endif

#if USE_VL53L0X
#include <Wire.h>
#include <VL53L0X.h>
VL53L0X tof;
#endif

// ================================================================
// THAM SO CHIEN THUAT
// ================================================================

constexpr uint32_t START_DEBOUNCE_MS = 35;
constexpr uint32_t PHASE_1_MS = 5000;

// Khong ping lien tuc. Jitter nho giup giam kha nang trung xung voi robot doi thu.
constexpr uint32_t US_PROBE_MIN_INTERVAL_MS = 45;
constexpr uint32_t US_PROBE_MAX_INTERVAL_MS = 70;
constexpr uint32_t US_JUKE_MIN_INTERVAL_MS  = 26;
constexpr uint32_t US_JUKE_MAX_INTERVAL_MS  = 36;

constexpr uint16_t US_MIN_CM = 3;
constexpr uint16_t US_MAX_CM = 55;
constexpr uint32_t US_TIMEOUT_US = 3500;  // Khoang 59 cm

constexpr uint32_t TOF_INTERVAL_MS = 50;  // Tot hon 20 ms cho muc tieu toi/den
constexpr uint16_t TOF_MIN_MM = 20;
constexpr uint16_t TOF_MAX_MM = 550;

constexpr uint32_t JUKE_MIN_MS = 75;       // Khong tin mot lan mat muc tieu qua som
constexpr uint32_t JUKE_DEFAULT_MS = 145;  // Dung khi Phase 1 khong khoa duoc doi thu
constexpr uint32_t JUKE_MAX_MS = 240;
constexpr uint8_t LOST_CONFIRM_COUNT = 3;

constexpr uint32_t COUNTER_BRAKE_MS = 15;

constexpr uint32_t COMBAT_US_MIN_INTERVAL_MS = 30;
constexpr uint32_t COMBAT_US_MAX_INTERVAL_MS = 42;
constexpr uint32_t US_FRESH_MS = 80;
constexpr uint32_t TOF_FRESH_MS = 110;
constexpr uint8_t TARGET_ACQUIRE_COUNT = 2;
constexpr uint8_t TARGET_LOST_COUNT = 3;

constexpr uint32_t RELOCK_REVERSE_DIRECTION_MS = 420;
constexpr uint32_t RELOCK_TIMEOUT_MS = 900;
constexpr uint32_t STRIKE_TOTAL_TIMEOUT_MS = 650;
constexpr uint16_t CONTACT_DISTANCE_CM = 14;
constexpr uint16_t CONTACT_HOLD_DISTANCE_CM = 17;
constexpr uint32_t CONTACT_TEST_MS = 100;
constexpr uint32_t ATTACK_BURST_MS = 80;
constexpr uint32_t ANCHOR_ESCAPE_MS = 65;
constexpr uint32_t FLANK_ARC_MS = 220;

// Thoi gian ngan hon ban 2-cam-bien vi chi nhin thay vach o phia truoc.
constexpr uint32_t BLIND_RUSH_MS = 70;
constexpr uint32_t SEARCH_DIRECTION_MS = 650;
constexpr uint32_t EDGE_REVERSE_MIN_MS = 65;
constexpr uint32_t EDGE_REVERSE_MAX_MS = 125;
constexpr uint32_t EDGE_CLEAR_CONFIRM_MS = 20;
constexpr uint32_t EDGE_TURN_MS = 160;

// Pin 2S cap thang cho TB6612; LM2596 chi cap 5 V cho ESP32/cam bien.
// Cac muc nay gioi han TT 6 V khi pin day 8.4 V.
constexpr int PWM_SEARCH = 90;
constexpr int PWM_JUKE = 190;
constexpr int PWM_APPROACH = 175;
constexpr int PWM_CONTACT_TEST = 190;
constexpr int PWM_ATTACK_BURST = 205;
constexpr int PWM_BLIND_RUSH = 175;
constexpr int PWM_ESCAPE = 160;
constexpr int PWM_FLANK_SLOW = 75;
constexpr int PWM_FLANK_FAST = 185;
constexpr int PWM_EDGE_REVERSE = 175;
constexpr int PWM_EDGE_TURN = 145;

enum MatchState {
  WAIT_START,
  PHASE_1_PROBING,
  PHASE_2_JUKE,
  PHASE_2_BRAKE,
  PHASE_3_RELOCK,
  PHASE_4_STRIKE,
  PHASE_5_RING_CONTROL
};

enum Phase5SubState {
  P5_REGULAR_TRACKING,
  P5_CONTACT_TEST,
  P5_ATTACK_BURST,
  P5_ANCHOR_ESCAPE,
  P5_FLANK_ARC,
  P5_EDGE_REVERSING,
  P5_EDGE_TURNING
};

enum Phase4SubState {
  P4_APPROACH,
  P4_CONTACT_TEST,
  P4_ATTACK_BURST
};

enum Alignment {
  ALIGNMENT_UNKNOWN,
  ALIGNMENT_FRONT
};

struct OpponentTelemetry {
  uint16_t usAttempts = 0;
  uint16_t usValidSamples = 0;
  uint16_t usTimeoutSamples = 0;

  uint16_t tofAttempts = 0;
  uint16_t tofValidSamples = 0;

  uint16_t distanceCm = 9999;
  uint8_t confidencePercent = 0;
  bool detected = false;
  Alignment alignment = ALIGNMENT_UNKNOWN;
};

OpponentTelemetry enemy;
MatchState currentState = WAIT_START;

constexpr size_t MAX_DISTANCE_SAMPLES = 105;
uint16_t usSamples[MAX_DISTANCE_SAMPLES];
uint16_t tofSamples[MAX_DISTANCE_SAMPLES];
size_t usSampleCount = 0;
size_t tofSampleCount = 0;

uint32_t phaseStartMs = 0;
uint32_t lastUsScanMs = 0;
uint32_t nextUsIntervalMs = US_PROBE_MIN_INTERVAL_MS;
uint32_t lastTofScanMs = 0;
uint32_t brakeStartMs = 0;
uint32_t combatStateStartMs = 0;
uint32_t lastCombatUsMs = 0;
uint32_t nextCombatUsIntervalMs = COMBAT_US_MIN_INTERVAL_MS;
uint32_t lastCombatTofMs = 0;
uint32_t predictiveRushStartMs = 0;
uint32_t searchDirectionStartMs = 0;
uint32_t edgeEscapeStartMs = 0;
uint32_t edgeClearStartMs = 0;
uint32_t tacticalActionStartMs = 0;

int jukeDirection = 1;  // 1: pivot trai, 2: pivot phai
int searchDirection = 1;
int edgeTurnDirection = 1;
int flankDirection = 1;
uint8_t consecutiveTargetMisses = 0;
uint8_t combatSeenStreak = 0;
uint8_t combatMissStreak = 0;
int combatUsCm = -1;
int combatTofMm = -1;
bool predictiveRushActive = false;
bool p5HadTarget = false;
Phase5SubState p5State = P5_REGULAR_TRACKING;
Phase4SubState p4State = P4_APPROACH;

// ================================================================
// KHAI BAO HAM
// ================================================================

void setMotor(int speed, uint8_t pwmPin, uint8_t in1, uint8_t in2);
void shortBrakeMotor(uint8_t pwmPin, uint8_t in1, uint8_t in2);
bool setupMotorPwm();
void writeMotorPwm(uint8_t pwmPin, uint8_t duty);
void motorsDrive(int leftSpeed, int rightSpeed);
void stopMotors();
void executeJuke(int direction);
void executeCounterBrake(int direction);

bool edgeDetected();
void enterEdgeEscape(uint32_t now);
bool startButtonPressed(uint32_t now);
int readUltrasonicCm();
int readToFMm();

void resetTelemetry();
void collectPhase1(uint32_t now);
void finalizePhase1();
bool targetLostConfirmed(uint32_t now);
uint16_t medianOf(uint16_t *values, size_t count);
void printTelemetry();
void resetCombatObservation(uint32_t now);
void updateCombatSensors(uint32_t now);
bool combatTargetSeen(uint32_t now);
uint16_t combatDistanceCm(uint32_t now);
void executeSearchTurn(int direction, int pwm);
void handlePhase3(uint32_t now);
void handlePhase4(uint32_t now);
void handlePhase5(uint32_t now);

void setup() {
  Serial.begin(115200);

  pinMode(PIN_START_BUTTON, INPUT_PULLUP);
  pinMode(PIN_US_TRIG, OUTPUT);
  pinMode(PIN_US_ECHO, INPUT);
  digitalWrite(PIN_US_TRIG, LOW);

  pinMode(PIN_LEFT_IN1, OUTPUT);
  pinMode(PIN_LEFT_IN2, OUTPUT);
  pinMode(PIN_RIGHT_IN1, OUTPUT);
  pinMode(PIN_RIGHT_IN2, OUTPUT);

  pinMode(PIN_EDGE_CENTER, INPUT);

  if (!setupMotorPwm()) {
    Serial.println("[LOI] Khong khoi tao duoc LEDC PWM.");
  }

  randomSeed(esp_random());

#if USE_VL53L0X
  Wire.begin(PIN_TOF_SDA, PIN_TOF_SCL);
  tof.setTimeout(30);
  if (!tof.init()) {
    Serial.println("[LOI] Khong tim thay VL53L0X.");
  } else {
    // 50 ms cho nhieu photon hon, on dinh hon voi vo den.
    tof.setMeasurementTimingBudget(50000);
    tof.startContinuous(TOF_INTERVAL_MS);
  }
#endif

  stopMotors();
  Serial.println("[SAN SANG] Cho trong tai ho, sau do bam nut START.");
}

void loop() {
  const uint32_t now = millis();

  switch (currentState) {
    case WAIT_START:
      stopMotors();
      if (startButtonPressed(now)) {
        resetTelemetry();
        phaseStartMs = now;
        lastUsScanMs = now;
        lastTofScanMs = now;
        nextUsIntervalMs = random(US_PROBE_MIN_INTERVAL_MS,
                                  US_PROBE_MAX_INTERVAL_MS + 1);
        currentState = PHASE_1_PROBING;
        Serial.println("[PHASE 1] Bat dau dem 5 giay va tham do.");
      }
      break;

    case PHASE_1_PROBING:
      stopMotors();
      collectPhase1(now);

      if (now - phaseStartMs >= PHASE_1_MS) {
        finalizePhase1();
        jukeDirection = (esp_random() & 1U) ? 1 : 2;
        printTelemetry();

        phaseStartMs = now;
        lastUsScanMs = now;
        nextUsIntervalMs = random(US_JUKE_MIN_INTERVAL_MS,
                                  US_JUKE_MAX_INTERVAL_MS + 1);
        consecutiveTargetMisses = 0;
        currentState = PHASE_2_JUKE;
        Serial.println("[PHASE 2] Bat dau pivot co phan hoi cam bien.");
      }
      break;

    case PHASE_2_JUKE: {
      const uint32_t elapsed = now - phaseStartMs;

      // Cam bien bien luon co quyen uu tien cao nhat.
      if (edgeDetected()) {
        enterEdgeEscape(now);
        Serial.println("[AN TOAN] Phat hien vach trang trong luc ne.");
        break;
      }

      executeJuke(jukeDirection);

      const bool lost = targetLostConfirmed(now);
      const bool sensorStop = enemy.detected && elapsed >= JUKE_MIN_MS && lost;
      const bool timedStop = (!enemy.detected && elapsed >= JUKE_DEFAULT_MS) ||
                             elapsed >= JUKE_MAX_MS;

      if (sensorStop || timedStop) {
        brakeStartMs = now;
        currentState = PHASE_2_BRAKE;
      }
      break;
    }

    case PHASE_2_BRAKE:
      if (edgeDetected()) {
        enterEdgeEscape(now);
      } else if (now - brakeStartMs < COUNTER_BRAKE_MS) {
        executeCounterBrake(jukeDirection);
      } else {
        stopMotors();
        resetCombatObservation(now);
        searchDirection = (jukeDirection == 1) ? 2 : 1;
        currentState = PHASE_3_RELOCK;
        Serial.println("[PHASE 3] Ket thuc ne, bat dau khoa lai muc tieu.");
      }
      break;

    case PHASE_3_RELOCK:
      handlePhase3(now);
      break;

    case PHASE_4_STRIKE:
      handlePhase4(now);
      break;

    case PHASE_5_RING_CONTROL:
      handlePhase5(now);
      break;
  }
}

// ================================================================
// THAM DO 5 GIAY
// ================================================================

void resetTelemetry() {
  enemy = OpponentTelemetry{};
  usSampleCount = 0;
  tofSampleCount = 0;
}

void collectPhase1(uint32_t now) {
  if (now - lastUsScanMs >= nextUsIntervalMs) {
    lastUsScanMs = now;
    nextUsIntervalMs = random(US_PROBE_MIN_INTERVAL_MS,
                              US_PROBE_MAX_INTERVAL_MS + 1);

    enemy.usAttempts++;
    const int cm = readUltrasonicCm();
    if (cm >= US_MIN_CM && cm <= US_MAX_CM) {
      enemy.usValidSamples++;
      if (usSampleCount < MAX_DISTANCE_SAMPLES) {
        usSamples[usSampleCount++] = static_cast<uint16_t>(cm);
      }
    } else {
      enemy.usTimeoutSamples++;
    }
  }

#if USE_VL53L0X
  if (now - lastTofScanMs >= TOF_INTERVAL_MS) {
    lastTofScanMs = now;
    enemy.tofAttempts++;
    const int mm = readToFMm();
    if (mm >= TOF_MIN_MM && mm <= TOF_MAX_MM) {
      enemy.tofValidSamples++;
      if (tofSampleCount < MAX_DISTANCE_SAMPLES) {
        tofSamples[tofSampleCount++] = static_cast<uint16_t>(mm);
      }
    }
  }
#endif
}

void finalizePhase1() {
  const float usRate = enemy.usAttempts
                           ? static_cast<float>(enemy.usValidSamples) / enemy.usAttempts
                           : 0.0f;
  const float tofRate = enemy.tofAttempts
                            ? static_cast<float>(enemy.tofValidSamples) / enemy.tofAttempts
                            : 0.0f;

  // ToF co chum hep hon, nen uu tien median ToF neu du mau hop le.
  if (tofSampleCount >= 5) {
    enemy.distanceCm = medianOf(tofSamples, tofSampleCount) / 10;
  } else if (usSampleCount >= 5) {
    enemy.distanceCm = medianOf(usSamples, usSampleCount);
  }

  const float fusedConfidence = USE_VL53L0X
                                    ? (0.55f * tofRate + 0.45f * usRate)
                                    : usRate;
  enemy.confidencePercent = static_cast<uint8_t>(
      constrain(static_cast<int>(fusedConfidence * 100.0f + 0.5f), 0, 100));

  enemy.detected = (tofRate >= 0.55f) || (usRate >= 0.45f);
  enemy.alignment = enemy.detected ? ALIGNMENT_FRONT : ALIGNMENT_UNKNOWN;
}

uint16_t medianOf(uint16_t *values, size_t count) {
  // Sap xep chen tai cho; voi toi da ~100 mau va chi chay mot lan thi du nhanh.
  for (size_t i = 1; i < count; ++i) {
    const uint16_t key = values[i];
    size_t j = i;
    while (j > 0 && values[j - 1] > key) {
      values[j] = values[j - 1];
      --j;
    }
    values[j] = key;
  }

  if (count == 0) return 9999;
  if (count & 1U) return values[count / 2];
  return static_cast<uint16_t>(
      (static_cast<uint32_t>(values[count / 2 - 1]) + values[count / 2]) / 2U);
}

// ================================================================
// PHASE 2: JUKE CO PHAN HOI
// ================================================================

bool targetLostConfirmed(uint32_t now) {
  if (now - lastUsScanMs < nextUsIntervalMs) {
    return consecutiveTargetMisses >= LOST_CONFIRM_COUNT;
  }

  lastUsScanMs = now;
  nextUsIntervalMs = random(US_JUKE_MIN_INTERVAL_MS,
                            US_JUKE_MAX_INTERVAL_MS + 1);

  const int cm = readUltrasonicCm();
  if (cm >= US_MIN_CM && cm <= US_MAX_CM) {
    consecutiveTargetMisses = 0;
  } else if (consecutiveTargetMisses < 255) {
    consecutiveTargetMisses++;
  }

  return consecutiveTargetMisses >= LOST_CONFIRM_COUNT;
}

int readUltrasonicCm() {
  digitalWrite(PIN_US_TRIG, LOW);
  delayMicroseconds(2);
  digitalWrite(PIN_US_TRIG, HIGH);
  delayMicroseconds(10);  // HC-SR04 can xung kich toi thieu 10 us
  digitalWrite(PIN_US_TRIG, LOW);

  const uint32_t duration = pulseIn(PIN_US_ECHO, HIGH, US_TIMEOUT_US);
  if (duration == 0) return -1;
  return static_cast<int>((duration * 343UL) / 20000UL);
}

int readToFMm() {
#if USE_VL53L0X
  const uint16_t mm = tof.readRangeContinuousMillimeters();
  if (tof.timeoutOccurred()) return -1;
  return mm;
#else
  return -1;
#endif
}

// ================================================================
// PHASE 3, 4, 5
// ================================================================

void resetCombatObservation(uint32_t now) {
  combatUsCm = -1;
  combatTofMm = -1;
  combatSeenStreak = 0;
  combatMissStreak = 0;
  lastCombatUsMs = now;
  lastCombatTofMs = now;
  nextCombatUsIntervalMs = random(COMBAT_US_MIN_INTERVAL_MS,
                                   COMBAT_US_MAX_INTERVAL_MS + 1);
  combatStateStartMs = now;
  predictiveRushActive = false;
  p5HadTarget = false;
}

bool combatTargetSeen(uint32_t now) {
  const bool usSeen = combatUsCm >= US_MIN_CM &&
                      combatUsCm <= US_MAX_CM &&
                      now - lastCombatUsMs <= US_FRESH_MS;

#if USE_VL53L0X
  const bool tofSeen = combatTofMm >= TOF_MIN_MM &&
                       combatTofMm <= TOF_MAX_MM &&
                       now - lastCombatTofMs <= TOF_FRESH_MS;
#else
  const bool tofSeen = false;
#endif

  return usSeen || tofSeen;
}

void updateCombatSensors(uint32_t now) {
  bool hasNewSample = false;

  if (now - lastCombatUsMs >= nextCombatUsIntervalMs) {
    combatUsCm = readUltrasonicCm();
    lastCombatUsMs = now;
    nextCombatUsIntervalMs = random(COMBAT_US_MIN_INTERVAL_MS,
                                     COMBAT_US_MAX_INTERVAL_MS + 1);
    hasNewSample = true;
  }

#if USE_VL53L0X
  if (now - lastCombatTofMs >= TOF_INTERVAL_MS) {
    combatTofMm = readToFMm();
    lastCombatTofMs = now;
    hasNewSample = true;
  }
#endif

  if (!hasNewSample) return;

  const uint32_t afterRead = millis();
  if (combatTargetSeen(afterRead)) {
    if (combatSeenStreak < 255) combatSeenStreak++;
    combatMissStreak = 0;
  } else {
    combatSeenStreak = 0;
    if (combatMissStreak < 255) combatMissStreak++;
  }
}

uint16_t combatDistanceCm(uint32_t now) {
#if USE_VL53L0X
  if (combatTofMm >= TOF_MIN_MM && combatTofMm <= TOF_MAX_MM &&
      now - lastCombatTofMs <= TOF_FRESH_MS) {
    return static_cast<uint16_t>(combatTofMm / 10);
  }
#endif

  if (combatUsCm >= US_MIN_CM && combatUsCm <= US_MAX_CM &&
      now - lastCombatUsMs <= US_FRESH_MS) {
    return static_cast<uint16_t>(combatUsCm);
  }
  return 9999;
}

void executeSearchTurn(int direction, int pwm) {
  pwm = constrain(pwm, 0, 255);
  if (direction == 1) {
    motorsDrive(-pwm, pwm);  // Xoay trai
  } else {
    motorsDrive(pwm, -pwm);  // Xoay phai
  }
}

void enterEdgeEscape(uint32_t now) {
  stopMotors();
  currentState = PHASE_5_RING_CONTROL;
  p5State = P5_EDGE_REVERSING;
  edgeEscapeStartMs = now;
  edgeClearStartMs = 0;
  edgeTurnDirection = (edgeTurnDirection == 1) ? 2 : 1;
  predictiveRushActive = false;
  p5HadTarget = false;
  Serial.println("[BIEN] Bat dau lui ngan de dua cam bien khoi vach trang.");
}

void handlePhase3(uint32_t now) {
  if (edgeDetected()) {
    enterEdgeEscape(now);
    return;
  }

  updateCombatSensors(now);
  const uint32_t elapsed = now - combatStateStartMs;

  if (combatSeenStreak >= TARGET_ACQUIRE_COUNT) {
    stopMotors();
    combatStateStartMs = millis();
    tacticalActionStartMs = combatStateStartMs;
    combatMissStreak = 0;
    p4State = P4_APPROACH;
    currentState = PHASE_4_STRIKE;
    Serial.println("[PHASE 3 -> 4] Da xac nhan muc tieu qua nhieu mau.");
    return;
  }

  if (elapsed >= RELOCK_TIMEOUT_MS) {
    stopMotors();
    p5State = P5_REGULAR_TRACKING;
    searchDirectionStartMs = now;
    predictiveRushActive = false;
    p5HadTarget = false;
    currentState = PHASE_5_RING_CONTROL;
    Serial.println("[PHASE 3 -> 5] Het timeout khoa muc tieu, chuyen sang tim kiem.");
    return;
  }

  const int direction = elapsed < RELOCK_REVERSE_DIRECTION_MS
                            ? searchDirection
                            : (3 - searchDirection);
  executeSearchTurn(direction, PWM_SEARCH);
}

void handlePhase4(uint32_t now) {
  if (edgeDetected()) {
    enterEdgeEscape(now);
    return;
  }

  updateCombatSensors(now);
  const bool seen = combatTargetSeen(now) && combatSeenStreak > 0;

  if (combatMissStreak >= TARGET_LOST_COUNT) {
    stopMotors();
    p5State = P5_REGULAR_TRACKING;
    searchDirectionStartMs = now;
    predictiveRushActive = false;
    p5HadTarget = false;
    currentState = PHASE_5_RING_CONTROL;
    Serial.println("[PHASE 4 -> 5] Mat muc tieu, huy chu trinh tan cong.");
    return;
  }

  if (now - combatStateStartMs >= STRIKE_TOTAL_TIMEOUT_MS) {
    stopMotors();
    p5State = P5_REGULAR_TRACKING;
    searchDirectionStartMs = now;
    predictiveRushActive = false;
    p5HadTarget = seen;
    currentState = PHASE_5_RING_CONTROL;
    Serial.println("[PHASE 4 -> 5] Het timeout tiep can, chuyen sang dieu khien san.");
    return;
  }

  switch (p4State) {
    case P4_APPROACH: {
      if (!seen) {
        executeSearchTurn(searchDirection, PWM_SEARCH);
        break;
      }

      const uint16_t distance = combatDistanceCm(now);
      if (distance <= CONTACT_DISTANCE_CM) {
        p4State = P4_CONTACT_TEST;
        tacticalActionStartMs = now;
        motorsDrive(PWM_CONTACT_TEST, PWM_CONTACT_TEST);
      } else {
        motorsDrive(PWM_APPROACH, PWM_APPROACH);
      }
      break;
    }

    case P4_CONTACT_TEST:
      motorsDrive(PWM_CONTACT_TEST, PWM_CONTACT_TEST);
      if (now - tacticalActionStartMs >= CONTACT_TEST_MS) {
        if (seen && combatDistanceCm(now) <= CONTACT_HOLD_DISTANCE_CM) {
          p4State = P4_ATTACK_BURST;
          tacticalActionStartMs = now;
        } else {
          p4State = P4_APPROACH;
        }
      }
      break;

    case P4_ATTACK_BURST:
      motorsDrive(PWM_ATTACK_BURST, PWM_ATTACK_BURST);
      if (now - tacticalActionStartMs >= ATTACK_BURST_MS) {
        if (seen && combatDistanceCm(now) <= CONTACT_HOLD_DISTANCE_CM) {
          stopMotors();
          flankDirection = (flankDirection == 1) ? 2 : 1;
          p5State = P5_ANCHOR_ESCAPE;
          tacticalActionStartMs = now;
          currentState = PHASE_5_RING_CONTROL;
          Serial.println("[ANTI-ANCHOR] Muc tieu van sat sau xung day, rut ra danh suon.");
        } else {
          p5State = P5_REGULAR_TRACKING;
          p5HadTarget = seen;
          predictiveRushActive = false;
          searchDirectionStartMs = now;
          currentState = PHASE_5_RING_CONTROL;
        }
      }
      break;
  }
}
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

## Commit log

2026-07-10 Làm phần mềm
2026-07-10 Add Sumo Robot firmware for ESP32
2026-07-10 Revert "Làm phần mềm"
    This reverts commit 40185a94a2bc0bf21145ecd74b3dd0eb3630589a.
2026-07-13 tạo thư mục hardware
2026-07-13 Thêm các thư mục
2026-07-13 sửa lại
2026-07-14 Added real assets to the repository.
    [Case.stl]
2026-07-14 Đẩy báo cáo cuối cùng
